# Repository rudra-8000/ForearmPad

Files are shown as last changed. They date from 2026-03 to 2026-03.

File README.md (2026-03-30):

# ForearmPad

> A wearable, touchless mouse input device for people with limited finger mobility — worn on the left forearm, controlled by the right hand.

ForearmPad turns a left forearm into a 15 cm virtual trackpad using an ultrasonic distance sensor and an ESP32 microcontroller. No finger dexterity required. No buttons to press. Gestures are detected by hovering and moving the right hand above the forearm, emitting Bluetooth HID mouse events to any connected device.

This project is being developed as a hardware input peripheral for the **[TimOS](https://github.com/theDapperFoxtrot/timos)** project by [the Dapper Foxtrot](https://github.com/theDapperFoxtrot) — an accessible input layer for VR that enables people who cannot use fine motor hand control to operate computers and VR applications autonomously.

---

## Demo

[![ForearmPad Demo]](https://www.youtube.com/watch?v=68rtDSnFRxo)

---

## Why This Exists

Most computer input devices — mice, trackpads, keyboards — assume fully functional hand and finger dexterity. For people with conditions like ALS, cerebral palsy, spinal cord injury, or other motor impairments, standard input hardware is a barrier rather than a tool.

ForearmPad is designed from the ground up for **input without finger use**. The forearm is a large, stable body surface that remains accessible even when hand function is significantly reduced. By pointing a single ultrasonic sensor along the forearm axis, we get a continuous 1D position reading that maps cleanly onto left click, right click, and scroll — the three most essential mouse actions.

This is part of a broader effort in the TimOS ecosystem to provide **input redundancy**: every meaningful computer action should be triggerable through multiple modalities, so that a user only needs *one* working input method.

---

## How It Works

The HC-SR04 ultrasonic sensor is mounted at the **wrist end** of the left forearm, pointed toward the elbow. It continuously measures how far the right hand is from the sensor as it hovers above the arm.

```
[SENSOR] ←──────────── 14 cm ────────────→ [ELBOW]
          ← LEFT zone  │  RIGHT zone →
          (0 – 9 cm)   │  (9 – 14 cm)
             LEFT CLICK │ RIGHT CLICK
          ↑ scroll up  ←→  ↓ scroll down
```

### Gesture Logic

| Gesture | How to perform | Output |
|---|---|---|
| **Left click** | Briefly dip right hand above wrist-side half and lift | Left mouse button click |
| **Right click** | Briefly dip right hand above elbow-side half and lift | Right mouse button click |
| **Scroll up** | Sweep right hand toward the sensor (wrist direction) | Mouse scroll up |
| **Scroll down** | Sweep right hand away from sensor (elbow direction) | Mouse scroll down |
| **No action** | Hand held still | Nothing (hover, no event) |

Clicks require the hand to be present for **35–500 ms**. Any motion during that window escalates to scroll mode and suppresses the click, preventing accidental clicks while scrolling. A 400 ms cooldown after scroll sessions prevents re-entry ghost clicks.

### Signal Processing

Raw sensor readings are smoothed with an **Exponential Moving Average (EMA)** filter (α = 0.25) running at ~33 Hz to suppress the HC-SR04's inherent ±3 mm noise without introducing perceptible latency on gesture edges.

---

## Hardware

| Component | Details |
|---|---|
| Microcontroller | ESP32 DevKit V1 |
| Sensor | HC-SR04 Ultrasonic Distance Sensor |
| Connectivity | Bluetooth Low Energy (BLE HID) |

### Wiring

| HC-SR04 | ESP32 |
|---|---|
| VCC | 3.3V |
| GND | GND |
| Trig | GPIO5 (D5) |
| Echo | GPIO18 (D18) |

> **Note:** HC-SR04 is rated for 5V but operates at 3.3V with reduced max range (~100 cm). For a 14 cm pad this is more than sufficient. If your module produces unreliable readings at 3.3V, power VCC from the 5V (VIN) pin and add a voltage divider (1kΩ + 2kΩ) on the Echo line to protect the ESP32 GPIO.

CAD files for a 3D-printable forearm mount are included in the [`CAD Files/`](./CAD%20Files/) directory.

---

## Software Setup

### Dependencies

- **Arduino IDE** with the [ESP32 board package](https://docs.espressif.com/projects/arduino-esp32/en/latest/installing.html) (espressif/arduino-esp32 ≥ 2.x)
- **[ESP32-BLE-Mouse](https://github.com/T-vK/ESP32-BLE-Mouse)** library by T-vK

### Known Issue: ESP32 Core 3.x Compatibility

If you are using ESP32 Arduino core **3.x**, the BLE-Mouse library has a type mismatch with the updated BLE API. Open `BleMouse.cpp` in your Arduino libraries folder and apply these two fixes:

**Line ~143:**
```cpp
// Before:
BLEDevice::init(bleMouseInstance->deviceName);
// After:
BLEDevice::init(String(bleMouseInstance->deviceName.c_str()));
```

**Line ~151:**
```cpp
// Before:
bleMouseInstance->hid->manufacturer()->setValue(bleMouseInstance->deviceManufacturer);
// After:
bleMouseInstance->hid->manufacturer()->setValue(String(bleMouseInstance->deviceManufacturer.c_str()));
```

### Flash

1. Open `ForearmPad.ino` in Arduino IDE
2. Select your ESP32 board and COM port
3. Upload

The device advertises itself over BLE as **"ForearmPad"**. Pair it like any Bluetooth mouse from your OS's Bluetooth settings.

---

## Tuning Parameters

All tuning constants are at the top of `ForearmPad.ino`:

| Parameter | Default | Effect |
|---|---|---|
| `PAD_MAX` | 14.0 cm | Total forearm pad length |
| `PAD_SPLIT` | 9.0 cm | Left / Right click zone boundary |
| `PAD_MIN` | 2.0 cm | Minimum distance (noise floor) |
| `EMA_ALPHA` | 0.25 | Smoothing factor — lower = smoother but more latency |
| `TAP_MIN_MS` | 35 ms | Minimum dwell to register a click |
| `TAP_MAX_MS` | 500 ms | Maximum dwell to still be a click (not a hold) |
| `SCROLL_DELTA` | 0.55 cm/sample | Minimum per-sample movement to enter scroll mode |
| `SCROLL_TICK` | 1.4 cm | Distance of hand travel per one scroll step |
| `POST_SCROLL_COOLDOWN_MS` | 400 ms | Lockout period after scroll ends, prevents ghost clicks |

---

## TimOS Integration

ForearmPad is being developed as a peripheral input device for **TimOS**, an open-source accessible input layer for VR built by [the Dapper Foxtrot](https://github.com/theDapperFoxtrot).

TimOS translates diverse inputs — head tracking, eye gaze, voice commands, controller collision, and assistive peripherals — into standard mouse, keyboard, and gamepad events. It runs as a SteamVR overlay, requiring no OS-level configuration, and is designed for people who cannot use conventional hand control to operate VR and desktop applications.

ForearmPad slots into the TimOS **input redundancy model**: users only need one working input method, and ForearmPad provides a hands-free, dexterity-free option for left/right click and scroll — the most critical mouse actions for navigating any interface.

> TimOS is currently in active development and not yet publicly available.

---

## Roadmap

- [ ] Multi-sensor version for 2D position tracking (absolute cursor movement)
- [ ] Double-tap gesture for drag lock
- [ ] Configurable zone split via serial command (no reflash needed)
- [ ] TimOS BLE client integration
- [ ] Battery-powered housing with forearm strap

---

## License

MIT

---

*Built as part of the accessibility hardware ecosystem for the TimOS project.*

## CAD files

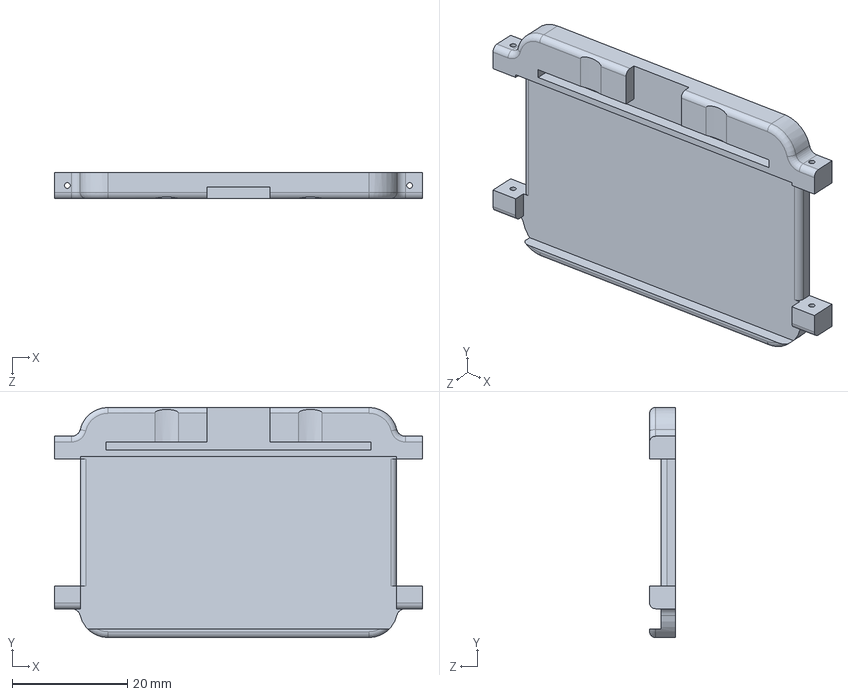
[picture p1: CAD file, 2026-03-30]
CAD Files/mount.SLDPRT
64.0 x 40.0 x 4.50 mm

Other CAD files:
CAD Files/mount.3mf

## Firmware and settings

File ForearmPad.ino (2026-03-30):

#include <Arduino.h>
#include <BleMouse.h>

#define TRIG_PIN   5
#define ECHO_PIN  18

constexpr float    PAD_MIN        =  2.0f;
constexpr float    PAD_MAX        = 14.0f;
constexpr float    PAD_SPLIT      =  9.0f;

constexpr uint32_t LOOP_MS        = 30;
constexpr float    EMA_ALPHA      = 0.25f;

// ── Click timing window ──────────────────────────────
constexpr uint32_t TAP_MIN_MS     = 35;    // ← NEW: hand must dwell ≥ this to register
constexpr uint32_t TAP_MAX_MS     = 500;   // hand must leave  ≤ this from entry

// ── Scroll ───────────────────────────────────────────
constexpr float    SCROLL_DELTA   = 0.55f;
constexpr float    SCROLL_TICK    = 1.4f;

// ── Re-entry guard after scrolling ──────────────────
constexpr uint32_t POST_SCROLL_COOLDOWN_MS = 400; // ← NEW: ignore new detections briefly

BleMouse bleMouse("ForearmPad", "ESP32", 100);

enum State { IDLE, HOVER, SCROLLING };
State    state        = IDLE;
float    ema          = -1.0f;
float    prevEma      = -1.0f;
float    entryEma     = -1.0f;
uint32_t entryMs      =  0;
float    scrollAcc    =  0.0f;
uint32_t lastMs       =  0;
bool     didScroll    = false;  // ← NEW: latched true once scroll happens in session
uint32_t scrollEndMs  =  0;    
 // ← NEW: timestamp of last scroll session end

float measureCm() {
  digitalWrite(TRIG_PIN, LOW);
  delayMicroseconds(2);
  digitalWrite(TRIG_PIN, HIGH);
  delayMicroseconds(10);
  digitalWrite(TRIG_PIN, LOW);
  long dur = pulseIn(ECHO_PIN, HIGH, 23200UL);
  return dur ? (dur * 0.01715f) : -1.0f;
}

bool inPad(float d) { return d >= PAD_MIN && d <= PAD_MAX; }

void goIdle(uint32_t now, bool fromScroll) {
  ema       = -1.0f;
  scrollAcc = 0.0f;
  didScroll = false;
  state     = IDLE;
  if (fromScroll) scrollEndMs = now;  // start cooldown timer
}

void setup() {
  Serial.begin(115200);
  pinMode(TRIG_PIN, OUTPUT);
  pinMode(ECHO_PIN, INPUT);
  digitalWrite(TRIG_PIN, LOW);
  bleMouse.begin();
  Serial.println("ForearmPad: waiting for BLE connection...");
}

void loop() {
  uint32_t now = millis();
  if (now - lastMs < LOOP_MS) return;
  lastMs = now;

  float raw     = measureCm();
  bool  present = inPad(raw);

  if (present)
    ema = (ema < 0.0f) ? raw : (EMA_ALPHA * raw + (1.0f - EMA_ALPHA) * ema);

  if (!bleMouse.isConnected()) return;

  switch (state) {

    case IDLE:
      if (present) {
        // ── Re-entry cooldown: skip new sessions right after scrolling ──
        if ((now - scrollEndMs) < POST_SCROLL_COOLDOWN_MS) break;  // ← NEW

        state     = HOVER;
        entryMs   = now;
        entryEma  = ema;
        prevEma   = ema;
        scrollAcc = 0.0f;
        didScroll = false;
      }
      break;

    case HOVER:
      if (!present) {
        uint32_t dwellMs = now - entryMs;
        // ── Only click if: no scroll occurred AND dwell was in [MIN, MAX] window ──
        if (!didScroll                   // ← NEW: suppress if any scroll happened
            && dwellMs >= TAP_MIN_MS     // ← NEW: minimum intentional contact
            && dwellMs <= TAP_MAX_MS) {
          uint8_t btn = (entryEma < PAD_SPLIT) ? MOUSE_LEFT : MOUSE_RIGHT;
          bleMouse.click(btn);
          Serial.printf("[CLICK] %s  @ %.1f cm  dwell=%ums\n",
                        btn == MOUSE_LEFT ? "LEFT " : "RIGHT",
                        entryEma, dwellMs);
        }
        goIdle(now, false);
      } else {
        float delta = ema - prevEma;
        if (fabsf(delta) >= SCROLL_DELTA) {
          didScroll = true;          // ← NEW: latch — this session now disqualified for click
          state     = SCROLLING;
          scrollAcc = delta;
        }
        prevEma = ema;
      }
      break;

    case SCROLLING:
      if (!present) {
        goIdle(now, true);  // triggers cooldown
      } else {
        float delta = ema - prevEma;
        scrollAcc += delta;
        while (scrollAcc >=  SCROLL_TICK) {
          bleMouse.move(0, 0, -1);
          scrollAcc -= SCROLL_TICK;
          Serial.println("↓ scroll down");
        }
        while (scrollAcc <= -SCROLL_TICK) {
          bleMouse.move(0, 0,  1);
          scrollAcc += SCROLL_TICK;
          Serial.println("↑ scroll up");
        }
        prevEma = ema;
      }
      break;
  }
}
